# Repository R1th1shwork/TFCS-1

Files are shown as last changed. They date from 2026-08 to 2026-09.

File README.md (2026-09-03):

# TFCS-1: Teensy Flight Computer & Climate Suite



> **WARNING: Active Development**Expect changes to hardware wiring, sensor selection, and software builds as this project continues through testing and validation.

> **AI Transparency Disclosure**All system architecture, hardware selection, circuit design, and physical builds are designed and wired by me. AI was used only as a sounding board for code formatting, debugging, and documentation polish. The soldering, hardware decisions, and flight-control logic are human-built.

**TFCS-1** is an open-source flight controller and environmental sensing platform built around the **Teensy 4.1**. It combines flight-control sensing, servo control, radio input, telemetry, and atmospheric data logging for experimental aircraft and environmental monitoring.

- **GitHub:** [github.com/R1th1shwork/TFCS-1](https://github.com/R1th1shwork/TFCS-1)

- **Stardance:** [stardance.hackclub.com/projects/49798](https://stardance.hackclub.com/projects/49798)

---

## Project Assets

### Images and Media

| File | Description |
| --- | --- |
| `Assets/ten.png` | Teensy 4.1 microcontroller, the brain of TFCS-1 |
| `Assets/rf.jpeg` | RadioLink R12F SBUS receiver test |
| `Assets/icm.jpeg` | ICM-20948 9-DOF IMU, borrowed for development |
| `Assets/schematics.jpeg` | Earlier wiring diagram for the flight controller |

### Videos

| File | Description |
| --- | --- |
| `TFCS-1_Stardance_Ailerons.mp4` | Aileron servo demonstration |
| `ailerons test.mp4` | Aileron test footage |

> **Full Video Demos:** [Google Drive Folder](https://drive.google.com/drive/folders/199b-1cK7TjypQ-vlO30ZAJLWgoHDL5SH)

### Firmware and Hardware Design Files

| File | Description |
| --- | --- |
| `TFCS-1_All_Surfaces.ino` | Flight-controller code for ailerons, elevator, and rudder |
| `TFCS_1_SBUS.ino` | RadioLink SBUS receiver test code |
| `Codes/New FC.kicad_sch` | Current KiCad schematic for the flight-controller architecture |

The current schematic is included in the `Codes` directory. It documents the planned controller, power, sensor, receiver, telemetry, and servo connections. The schematic is being updated as the sensor suite is tested and final component choices are confirmed.

---

## Table of Contents

- [Why I Built This](#why-i-built-this)

- [Story / Behind the Scenes](#story--behind-the-scenes)

- [Current Status](#current-status)

- [Hardware](#hardware)

- [Wiring Instructions](#wiring-instructions)

- [Schematic and PCB Design](#schematic-and-pcb-design)

- [Control Surfaces](#control-surfaces)

- [Software](#software)

- [Setup](#setup)

- [Telemetry](#telemetry)

- [Challenges and Fixes](#challenges-and-fixes)

- [Roadmap](#roadmap)

- [Future Funding and BOM](#future-funding-and-bom)

- [Equipment Status](#equipment-status)

- [Testing Plan](#testing-plan)

- [Contributing](#contributing)

- [Author](#author)

- [Acknowledgments](#acknowledgments)

- [Disclaimer](#disclaimer)

---

## Why I Built This

I am a 16-year-old maker obsessed with flight. I did not start with a kit or a pre-built flight controller. I started with a soldering iron, a breadboard, and the determination to understand every wire and every line of code that keeps a plane in the air.

This project exists because:

- I want to **learn** flight-controller tuning, sensor fusion, and embedded systems from first principles.

- I want to **open-source** every finding, failure, and fix so the next builder does not start from zero.

- I believe the best way to learn is to build, break, and rebuild, one test at a time.

---

## Story / Behind the Scenes

### The Beginning

The Teensy 4.1 arrived from my tutor, a 600 MHz board I had been reading about for months. The first time the orange LED blinked, I knew this was real. Then came the ICM-20948, the 9-DOF IMU that was supposed to be the heart of the system. It did not work reliably. An I2C scan found it at `0x68`, but the moment I tried to read data, the bus could hang. No pull-up resistors, possible logic-level issues, or simply inexperience could have contributed. I spent hours staring at wires that refused to talk.

### The Breakthrough

I switched to the MPU-6050. Cheap, common, and suddenly it just worked. Data flowed. Numbers moved when I tilted the board. I connected the first servo and watched a control surface respond to my hands. That moment, seeing physics turn into servo motion, is when TFCS-1 became more than a project. It became a flight controller.

### The Reality Check

Not everything worked. Pin 8 was unreliable for my servo setup. The ICM-20948 still needs further debugging and testing. I salvaged wings from an old RC plane, pulled servos from crashed airframes, and learned that “working” in electronics often means “working after the 47th try.” Every buzz, every jitter, and every frozen I2C bus taught me something.

The sensor suite is also evolving through testing. I am currently validating the PMS5003, SCD40, MQ-135, BME680, GPS, compass, and other modules before committing to the final PCB layout. This is intentional: I want the final board to be based on tested sensors rather than assumptions.

### Why Open Source?

Because I learned from open-source projects. Because someone else out there is 16 years old, staring at a breadboard, wondering why their sensor will not respond. This is for them. This is for the builders who learn by breaking things.

---

## Current Status

| Module | Status | Notes |
| --- | --- | --- |
| MPU-6050 roll and pitch | Done | Working reliably on the bench |
| Elevator servo | Done | Pin 5, 40–140 degrees |
| Rudder servo | Done | Pin 6, 60–120 degrees |
| Aileron servos | Done | Pins 9 and 10, 40–140 degrees |
| Low-pass filter | Done | `ALPHA = 0.15` reduces jitter |
| Deadband | Done | `0.8 degrees` reduces servo buzzing |
| Serial telemetry | Done | 115200 baud |
| Flight-control logic | Bench tested | Roll and pitch correction logic implemented |
| RadioLink SBUS receiver | Done | Six channels reading correctly |
| PMS5003 particulate sensor | Tested | PM1.0, PM2.5, and PM10 data received |
| SCD40 CO2 sensor | Tested | CO2, temperature, and humidity data received |
| MQ-135 gas sensor | Tested | Raw analogue gas-trend data received; calibration still required |
| BME680 | Planned | To be integrated after current sensor validation |
| M10 GPS | Planned / integrating | UART position and flight-data testing |
| Compass | Planned / integrating | I2C heading testing and calibration required |
| SD-card logging | In progress | CSV logging architecture planned |
| RF telemetry | In progress | Packet architecture being tested |
| OLED ground receiver | Planned | Nano-based receiver display |
| Teensy 4.1 integration | In progress | Borrowed development unit |
| ICM-20948 9-DOF fusion | In progress | Needs debugging and validation |
| FPV system | Planned | 5.8 GHz camera and transmitter |
| Current schematic | Added | `Codes/New FC.kicad_sch` |
| Final custom PCB | Planned | Will be designed after the final sensor set is validated |

**Current test platform:** E-flite Apprentice S1E, 1500 mm wingspan, 840 KV motor.

> **Note:** The Apprentice is heavily damaged after a crash and cannot currently be flown. It is being used as a bench-test body and mechanical reference. Final flight testing will require an appropriate airframe, supervision, and any permissions required by the test location.

---

## Hardware

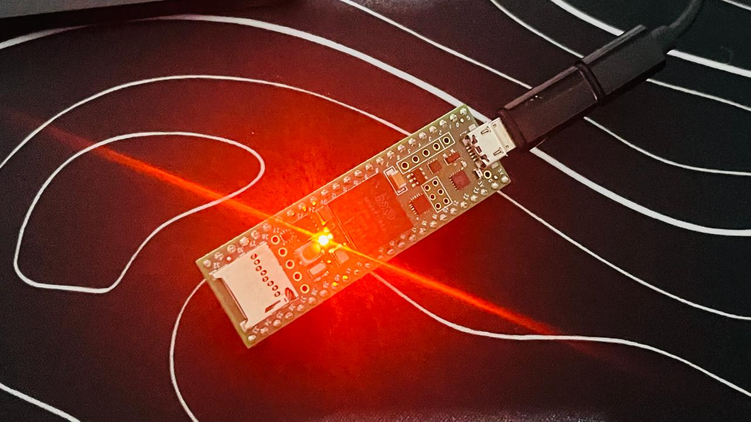
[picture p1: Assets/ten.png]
Teensy 4.1 Microcontroller


### Compute and Avionics

| Component | Model | Specs | Status |
| --- | --- | --- | --- |
| Primary controller | Teensy 4.1 | 600 MHz ARM Cortex-M7, 1 MB RAM | **BORROWED** |
| Development controller | Arduino Uno R3 | 16 MHz ATmega328P | Owned |
| Current IMU | MPU-6050 | 6-DOF accelerometer and gyroscope | Owned |
| Future IMU | ICM-20948 | 9-DOF accelerometer, gyroscope, and magnetometer | **BORROWED** |
| GPS module | M10-based GPS module | UART, position and timing data | Being integrated |
| Compass | External I2C magnetometer | Heading reference | To be tested |
| Radio receiver | RadioLink R12F | SBUS receiver | Owned |
| Radio transmitter | RadioLink T12D | 12 channels | Owned |
| Environmental sensors | PMS5003, SCD40, MQ-135, BME680 | Particulate, CO2, gas-trend, and atmospheric data | Being validated |

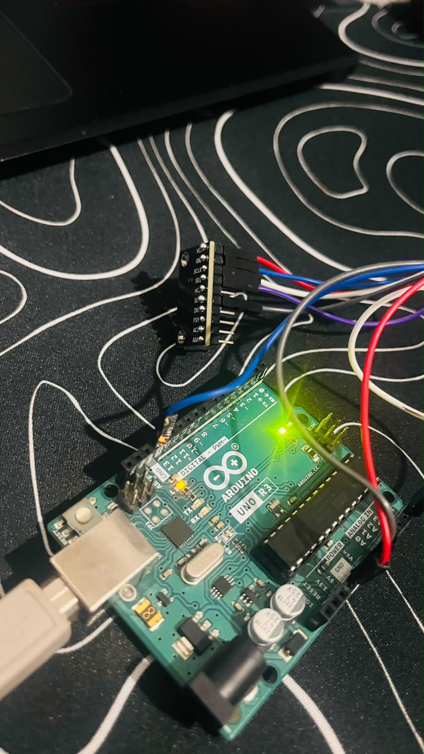
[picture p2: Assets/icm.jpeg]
ICM-20948 9-DOF IMU


### Actuators

| Component | Pin | Range | Status |
| --- | --- | --- | --- |
| Left aileron | 9 | 40–140 degrees | Owned |
| Right aileron | 10 | 40–140 degrees | Owned |
| Elevator | 5 | 40–140 degrees | Owned |
| Rudder | 6 | 60–120 degrees | Owned |
| ESC | — | 30 A with BEC | Owned |

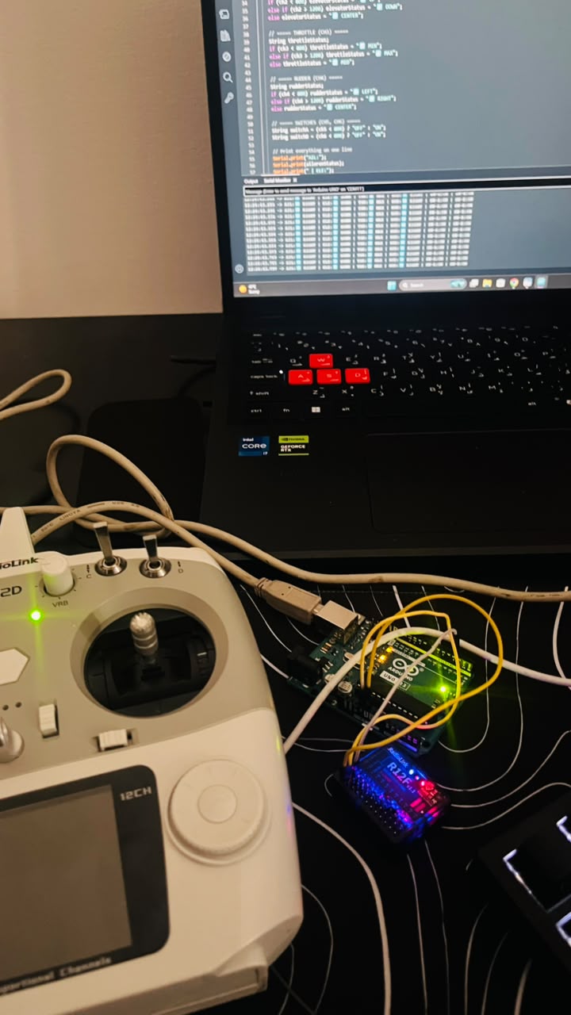
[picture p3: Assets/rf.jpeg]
RadioLink R12F SBUS Receiver


### Power

| Component | Specs | Status |
| --- | --- | --- |
| UBEC | 7 A, 5 V output | Owned |
| Battery | 4S 3000 mAh | To be purchased or supplied for final flight testing |
| Power distribution | Custom board or final PCB power section | Planned |

### Current and Planned Additions

- [x] Current schematic added to `Codes/New FC.kicad_sch`

- [x] PMS5003 tested

- [x] SCD40 tested

- [x] MQ-135 tested as a raw gas-trend sensor

- [ ] Teensy 4.1 full integration

- [ ] BME680 integration

- [ ] M10 GPS integration

- [ ] Compass integration and calibration

- [ ] MicroSD card logging

- [ ] RF telemetry

- [ ] OLED ground receiver

- [ ] FPV camera and VTX

- [ ] Final sensor validation

- [ ] Final custom PCB design and fabrication

- [ ] Airspeed sensor integration

- [ ] Professional barometer integration

---

## Wiring Instructions

> **Note:** Pin assignments below describe the current development architecture. They may change as the final sensor and controller configuration is validated.

### MPU-6050 and ICM-20948

| Pin | Teensy 4.1 | Arduino Uno | Function |
| --- | --- | --- | --- |
| VCC | 3.3 V | 3.3 V | Check the breakout-board voltage requirements |
| GND | GND | GND | Ground |
| SDA | 18 | A4 | I2C data |
| SCL | 19 | A5 | I2C clock |

### M10 GPS Module

| GPS pin | Controller connection | Function |
| --- | --- | --- |
| VCC | Regulated supply specified by the module | Power |
| GND | Common GND | Ground |
| TX | Hardware UART RX | GPS NMEA data |
| RX | Hardware UART TX, optional | GPS configuration |
| SDA/SCL | Only if the module is configured for I2C | Optional alternate interface |
| PPS | Optional digital input | Timing pulse |

The GPS and PMS5003 are both serial devices. They must not share the same UART receive pin at the same time. A second UART, a tested software UART, an external UART bridge, or a second controller may be required for simultaneous use.

### Compass

| Compass pin | Controller connection | Function |
| --- | --- | --- |
| VCC | Correct regulated voltage for the breakout | Power |
| GND | Common GND | Ground |
| SDA | I2C SDA | Heading data |
| SCL | I2C SCL | I2C clock |

The compass and MPU6050 can share the same I2C bus if their addresses do not conflict. The compass must be mounted away from motors, ESCs, high-current battery wires, and ferromagnetic hardware. It requires calibration and tilt-compensated sensor fusion before its output can be used as a reliable aircraft yaw estimate.

### RadioLink R12F SBUS

| Pin | Teensy 4.1 | Arduino Uno | Function |
| --- | --- | --- | --- |
| VCC | 5 V | 5 V | Power |
| GND | GND | GND | Ground |
| SBUS signal | Pin 3 or a suitable hardware serial input | Pin 3 during development | Receiver data |

### Servos

| Component | Teensy 4.1 | Arduino Uno | Wire/function |
| --- | --- | --- | --- |
| Elevator signal | Pin 5 | Pin 5 | Orange signal wire |
| Rudder signal | Pin 6 | Pin 6 | Orange signal wire |
| Left aileron signal | Pin 9 | Pin 9 | Orange signal wire |
| Right aileron signal | Pin 10 | Pin 10 | Orange signal wire |
| Servo VCC | External 5 V BEC | External 5 V BEC | Red wire |
| Servo GND | Common GND | Common GND | Brown or black wire |

### Power

| Connection | Description |
| --- | --- |
| UBEC input | Battery input within the UBEC’s specified range |
| UBEC output | Regulated 5 V for the controller or approved peripherals |
| Sensor rails | Use the correct 3.3 V or 5 V rail for each breakout board |
| RF module rail | Use a stable regulated 3.3 V supply and local decoupling |
| Ground | Connect all signal-system grounds together |

Never connect a raw LiPo battery directly to a controller or sensor. Always verify polarity, voltage, and current capacity before powering the system.

### Quick Reference

| Component | Power | Ground | Signal |
| --- | --- | --- | --- |
| MPU-6050 | 3.3 V or approved breakout voltage | GND | SDA to A4, SCL to A5 |
| Compass | Approved breakout voltage | GND | SDA to A4, SCL to A5 |
| M10 GPS | Approved module voltage | GND | UART TX to controller RX |
| RadioLink R12F | 5 V | GND | SBUS input |
| PMS5003 | Usually 5 V | GND | UART TX input |
| SCD40 | Approved breakout voltage | GND | SDA to A4, SCL to A5 |
| MQ-135 | Usually 5 V | GND | AOUT to analogue input |
| Elevator | External 5 V BEC | Common GND | Pin 5 |
| Rudder | External 5 V BEC | Common GND | Pin 6 |
| Left aileron | External 5 V BEC | Common GND | Pin 9 |
| Right aileron | External 5 V BEC | Common GND | Pin 10 |

---

## Schematic and PCB Design

The current schematic has now been added to the repository at:

```
Codes/New FC.kicad_sch
```
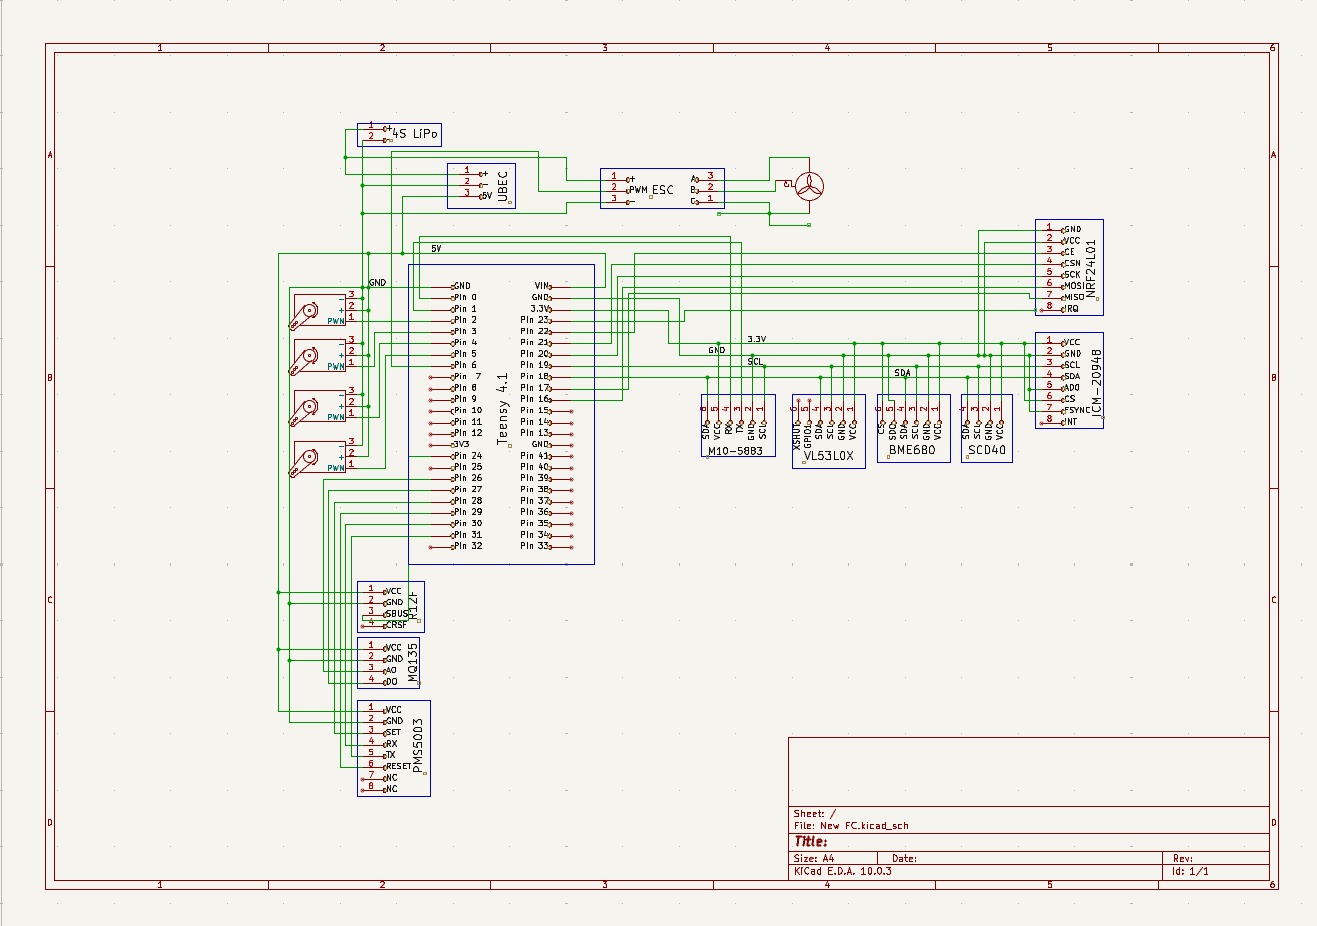
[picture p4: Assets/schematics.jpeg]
schematics


This file represents the current electrical architecture and is being updated as the sensor suite is tested. It includes the controller, power rails, sensor interfaces, receiver input, telemetry interfaces, and servo outputs.

The final PCB has **not** yet been fabricated. This is intentional because the sensor set and exact component choices are still being validated. The final board should be based on tested sensors, confirmed footprints, verified voltage levels, and measured power requirements.

The next hardware-design stage is a modular Rev A PCB design with removable connectors for the sensors. This allows the sensor models to be changed without redesigning the complete board. After the final sensor set is confirmed through bench testing, a final Rev B PCB will be designed and fabricated.

### Planned PCB interfaces

| Interface | Purpose |
| --- | --- |
| Controller headers | Teensy 4.1 connection |
| I2C headers | MPU6050, compass, SCD40, BME680, and compatible sensors |
| GPS UART header | M10 GPS connection |
| Environmental UART header | PMS5003 connection |
| Analogue header | MQ-135 and future analogue sensors |
| SPI header | SD card and telemetry peripherals |
| SBUS header | RadioLink receiver |
| Servo headers | Aileron, elevator, and rudder outputs |
| Power section | Battery input, regulated 5 V, regulated 3.3 V, protection, and test points |

> **Design status:** Schematic added. Final PCB fabrication is pending final sensor validation and confirmed component selection.

---

## Control Surfaces

| Axis | Surface | Pin | Range | Response |
| --- | --- | --- | --- | --- |
| Pitch | Elevator | 5 | 40–140 degrees | Nose attitude correction |
| Yaw | Rudder | 6 | 60–120 degrees | Directional correction |
| Roll | Left aileron | 9 | 40–140 degrees | Mirrored roll response |
| Roll | Right aileron | 10 | 40–140 degrees | Mirrored roll response |

**Neutral position for all servos:** 90 degrees.

---

## Software

### Current Features

| Feature | Implementation | Status |
| --- | --- | --- |
| I2C communication | `Wire` library | Done |
| Angle calculation | Accelerometer-based roll and pitch | Done |
| Digital filtering | Exponential moving average, `ALPHA = 0.15` | Done |
| Deadband | `0.8 degrees` | Done |
| Servo control | Four servos | Bench tested |
| Telemetry output | Serial Monitor at 115200 baud | Done |
| SBUS receiver | RadioLink R12F, six channels | Done |
| PMS5003 reading | Serial particulate data | Tested |
| SCD40 reading | I2C CO2, temperature, and humidity | Tested |
| MQ-135 reading | Analogue raw trend data | Tested; calibration pending |

### Control Loop

| Parameter | Value |
| --- | --- |
| Loop rate | 50 Hz, 20 ms |
| Filter | Exponential moving average |
| Alpha | 0.15 |
| Deadband | 0.8 degrees |
| Telemetry baud | 115200 |

### Key Code Snippet

```cpp
// Exponential Moving Average Filter
filteredPitch = (ALPHA * rawPitch) + ((1.0 - ALPHA) * filteredPitch);

// Deadband to prevent servo buzzing
if (abs(filteredPitch) < 0.8) {
  elevatorPos = 90;
}

// Map to servo positions
elevatorPos = map(filteredPitch, -20, 20, 140, 40);
```

---

## Setup

### 1. Install Libraries

```cpp
#include <Wire.h>    // I2C communication
#include <Servo.h>   // Servo control
#include <sbus.h>    // SBUS receiver
```

Additional sensor libraries will be added once each sensor is confirmed and the final controller platform is locked.

### 2. Upload

1. Select the correct board, either **Arduino Uno** for development or **Teensy 4.1** for the main controller.

1. Select the correct COM port.

1. Upload the firmware.

1. Open Serial Monitor at **115200 baud**.

### 3. Bench Test Procedure

| Test | Expected behavior |
| --- | --- |
| Hold board level | Servos remain near 90 degrees |
| Tilt nose down | Elevator responds in the configured direction |
| Tilt nose up | Elevator responds in the configured direction |
| Tilt left | Ailerons respond in opposite directions |
| Tilt right | Ailerons respond in opposite directions |
| Rotate compass | Heading changes after calibration |
| Expose PMS5003 to changing air conditions | PM readings respond after the sensor’s response delay |
| Change CO2 conditions safely | SCD40 reading changes over time |
| Move MQ-135 near a controlled test source | Raw trend value changes; no uncalibrated ppm claim |

All motor and propeller testing must be performed safely and separately from sensor and servo bench testing.

---

## Telemetry

```
P:0.0 deg (Elev:90 deg) | R:0.0 deg (Rudd:90 deg) | A:90 deg
P:-5.2 deg (Elev:77 deg) | R:0.0 deg (Rudd:90 deg) | A:77 deg
P:10.1 deg (Elev:65 deg) | R:0.0 deg (Rudd:90 deg) | A:65 deg
```

**Key:**

- `P`: Filtered pitch angle in degrees

- `Elev`: Elevator position

- `R`: Filtered roll angle in degrees

- `Rudd`: Rudder position

- `A`: Aileron position

The planned environmental telemetry will include CO2, PM1.0, PM2.5, PM10, temperature, humidity, pressure, GPS position, battery state, and sensor-health flags. The RF packet layout will be kept within the selected radio’s payload limit, with environmental and flight-status data split into separate packets where necessary.

---

## Challenges and Fixes

| Challenge | Solution |
| --- | --- |
| ICM-20948 not working reliably | Switched to the MPU-6050 for current development |
| Servo jitter | Added low-pass filtering with `ALPHA = 0.15` |
| Servo buzzing at level | Added a `0.8 degree` deadband |
| Pin 8 unreliable for a servo | Switched to Pins 5, 6, 9, and 10 |
| MPU not responding | Fixed wiring and added debug code |
| Servos moving in the same direction | Added mirrored mounting logic |
| I2C hanging | Improved wiring and added pull-up resistors where required |
| SBUS receiver not reading | Corrected signal wiring and installed the SBUS library |
| PMS5003 serial testing | Tested the sensor independently before integration |
| Changing sensor list | Using modular connectors and delaying final PCB fabrication |
| RF payload size | Splitting telemetry into smaller packets within the radio limit |

---

## Roadmap

### Immediate

- [x] Add the current KiCad schematic to `Codes/New FC.kicad_sch`

- [x] Test the PMS5003

- [x] Test the SCD40

- [x] Test the MQ-135 raw reading

- [ ] Complete Teensy 4.1 integration

- [ ] Integrate the M10 GPS

- [ ] Integrate and calibrate the compass

- [ ] Integrate the BME680

- [ ] Add SD-card CSV logging

- [ ] Test RF telemetry

- [ ] Build the OLED ground receiver

### Next Stage

- [ ] Validate the complete sensor suite on the bench

- [ ] Record repeatable environmental test data

- [ ] Create the modular Rev A PCB layout

- [ ] Verify all footprints, voltage rails, and power requirements

- [ ] Test the full controller with motors disconnected

- [ ] Integrate the final sensor set into the aircraft

### Future

- [ ] Fabricate the final custom PCB after sensor validation

- [ ] Full 6-axis sensor fusion using Madgwick or Mahony filtering

- [ ] MAVLink telemetry protocol

- [ ] Waypoint navigation

- [ ] Ground station for Android or PC

- [ ] AI-assisted flight tuning

- [ ] Airspeed-sensor integration

- [ ] Professional barometer integration

- [ ] FPV system integration

- [ ] Authorised real-flight testing

---

## Future Funding and BOM

With funding from Stardance, the sensor suite will become a much more complete and testable system. The funding will help me purchase higher-quality components and validate the Teensy 4.1 flight controller under real test conditions.

The exact sensor selection is still being validated. I have intentionally kept the final PCB fabrication separate from the initial sensor testing so that the final board is based on confirmed components rather than untested assumptions.

### Full BOM

| Item | Description | Qty | Price (AED) | Price (USD) | Link |
| --- | --- | --- | --- | --- | --- |
| SLONWAKE 1W VTX + 1500TVL Camera | 5.8 GHz 48CH FPV transmitter with camera | 1 | 151.95 | 41.36 | [AliExpress](https://ar.aliexpress.com/item/1005008177732104.html) |
| GY-63 MS5611 Barometer | High-precision air-pressure sensor module | 1 | 16.69 | 4.54 | [AliExpress](https://ar.aliexpress.com/item/32981169861.html) |
| MS4525DO Airspeed Sensor | Differential-pressure module with Pitot tube kit | 1 | 107.19 | 29.18 | [AliExpress](https://ar.aliexpress.com/item/1005009943453550.html) |
| 4S 3000 mAh LiPo Battery | 14.8 V, 60C RC battery with XT60 connector | 1 | 141.86 | 38.62 | [AliExpress](https://ar.aliexpress.com/item/1005010778424365.html) |
| SX1278 LoRa Ra-01 Module | 433 MHz long-range telemetry module, pack of 2 | 2 | 19.60 | 5.34 | [AliExpress](https://ar.aliexpress.com/item/1005007345198584.html) |
| BSS138 Logic Level Converter | Bidirectional 4-channel 3.3 V to 5 V converter | 1 | 10.00 | 2.72 | [Noon](https://www.noon.com/uae-en/bss138-logic-level-converter-bi-directional-4-channel-3-3v-5v-bi-directional/ZF14BBDADB787D14A80DAZ/p/) |
| MPU-9250 9-Axis IMU | Gyroscope, accelerometer, and magnetometer sensor | 1 | 20.00 | 5.44 | [Noon](https://www.noon.com/uae-en/mpu-9250-gy-9250-9-axle-16-bit-gyroscope-acceleration-magnetic-sensor-3-5v/ZAC72641E953208FED97AZ/p/) |
| BMP280 Barometer | Temperature and atmospheric-pressure sensor | 1 | 6.02 | 1.64 | [AliExpress](https://ar.aliexpress.com/item/1005012294605575.html) |
| AliExpress Shipping | Shipping fee for AliExpress order | 1 | 32.28 | 8.79 | — |
| UAE Import Tax | Estimated import tax and clearance fees | 1 | 40.00 | 10.90 | — |
| **GRAND TOTAL** |  |  | **541.38** | **147.50** |  |

*Exchange rate used in the original estimate: 1 USD = 3.6725 AED.*

### What This Funding Will Unlock

- Complete Teensy 4.1 flight-controller integration

- Higher-quality IMU, barometer, airspeed, telemetry, and FPV hardware

- Real bench and authorised flight testing

- Environmental sensor validation and data logging

- Modular PCB design followed by final PCB fabrication after the sensor set is confirmed

- Open-source release of firmware, schematic files, and future PCB design files

---

## Equipment Status

| Component | Status | Source |
| --- | --- | --- |
| Teensy 4.1 | **BORROWED** | Tutor, three months |
| ICM-20948 | **BORROWED** | Tutor, three months |
| MPU-6050 | Owned | — |
| Arduino Uno | Owned | — |
| M10 GPS module | Owned or being integrated | — |
| E-flite Apprentice S1E | **BROKEN** | Crashed, used for bench testing |
| Servos, four units | Owned | Recovered from old plane |
| 7 A UBEC | Owned | — |
| ESC | Owned | — |
| RadioLink T12D and R12F | Owned | Recently purchased |

**Special thanks:** A huge thank you to my tutor for lending me the expensive components, especially the Teensy 4.1 and ICM-20948. Without that support, this project would not be possible.

---

## Testing Plan

The project is being tested in stages. First, each sensor and interface is tested independently. Next, the controller, telemetry, logging, and sensor suite are tested together on the bench. After the final sensor choices are confirmed, the modular PCB design will be updated and the final PCB can be fabricated.

For flight testing, I will use an appropriate airframe and conduct testing only with suitable supervision, safety procedures, and any permissions required by the location. The damaged Apprentice is not being treated as a flyable aircraft.

### Validation evidence planned

- Sensor readings recorded over time

- CSV logs from the SD card

- GPS position and timing data

- IMU and compass calibration results

- RF packet-loss and range tests

- Servo-response and control-surface tests

- Power-rail voltage measurements

- Photographs of the assembled electronics

- Schematic and PCB design exports

- Flight-test videos and logs when authorised and safe

---

## Contributing

This is open-source and contributions are welcome.

### How to Contribute

1. Fork the repository.

1. Create a feature branch.

1. Commit your changes.

1. Push the branch.

1. Open a Pull Request with a clear explanation of the changes.

### Areas Needing Help

- Testing on different hardware

- Documentation improvements

- Modular PCB design

- Sensor-fusion algorithms

- Telemetry protocols

- Ground-station software

- Environmental-data visualisation

- Flight-test planning and safety review

---

## Author

**Rithish** — 16-year-old maker with a passion for flight and embedded systems.

- **GitHub:** [github.com/R1th1shwork](https://github.com/R1th1shwork)

- **Project:** [github.com/R1th1shwork/TFCS-1](https://github.com/R1th1shwork/TFCS-1)

- **Stardance:** [stardance.hackclub.com/projects/49798](https://stardance.hackclub.com/projects/49798)

---

## Acknowledgments

- **My tutor** — For lending critical components.

- **The Arduino community** — For open-source libraries and support.

- **The Teensy community** — For the incredible Teensy platform.

- **Open-source hardware and software contributors** — For making it possible to learn by building.

---

## Disclaimer

> This project is for educational and experimental purposes only. Always test flight hardware thoroughly before actual flight operations. Follow applicable aviation, venue, and safety requirements. The author is not responsible for damages or injuries resulting from the use of this hardware or software.

---

<p align="center">
<i>Built with passion, powered by curiosity, and tested on borrowed equipment.</i>  

  <b>Fly safe, have fun, and learn something new.</b>
</p> <p align="right"><i>Last Updated: September 2026</i></p>

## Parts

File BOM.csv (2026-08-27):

Item | Description | Qty | Price (AED) | Price (USD) | Link
SLONWAKE 1W VTX + 1500TVL Camera | 5.8GHz 48CH FPV Transmitter with Camera | 1 | 151.95 | 41.36 | https://ar.aliexpress.com/item/1005008177732104.html
GY-63 MS5611 Barometer | High Precision Air Pressure Sensor Module | 1 | 16.69 | 4.54 | https://ar.aliexpress.com/item/32981169861.html
MS4525DO Airspeed Sensor | Differential Pressure Module with Pitot Tube Kit | 1 | 107.19 | 29.18 | https://ar.aliexpress.com/item/1005009943453550.html
4S 3000mAh LiPo Battery | 14.8V 60C RC Battery with XT60 Connector | 1 | 141.86 | 38.62 | https://ar.aliexpress.com/item/1005010778424365.html
SX1278 LoRa Ra-01 Module | 433MHz Long-range Telemetry Module (Pack of 2) | 2 | 19.60 | 5.34 | https://ar.aliexpress.com/item/1005007345198584.html
BSS138 Logic Level Converter | Bi-Directional 4-Channel 3.3V-5V | 1 | 10.00 | 2.72 | https://www.noon.com/uae-en/bss138-logic-level-converter-bi-directional-4-channel-3-3v-5v-bi-directional/ZF14BBDADB787D14A80DAZ/p/
MPU-9250 9-Axle IMU | Gyro + Accelerometer + Magnetometer Sensor | 1 | 20.00 | 5.44 | https://www.noon.com/uae-en/mpu-9250-gy-9250-9-axle-16-bit-gyroscope-acceleration-magnetic-sensor-3-5v/ZAC72641E953208FED97AZ/p/
BMP280 Barometer | Temperature + Humidity + Atmospheric Pressure Sensor (3.3V) | 1 | 6.02 | 1.64 | https://ar.aliexpress.com/item/1005012294605575.html
AliExpress Shipping | Shipping Fee for AliExpress Order | 1 | 32.28 | 8.79
UAE Import Tax | Estimated Import Tax & Clearance Fees (5% + Handling) | 1 | 40.00 | 10.90
TOTAL ITEMS
GRAND TOTAL (AED) |  |  | 541.38 | 147.50

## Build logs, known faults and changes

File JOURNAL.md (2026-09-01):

# TFCS-1 Project Journal

**Project:** TFCS-1: Teensy Flight Computer & Climate Suite  
**Author:** Rithish (16-year-old maker)  
**Total Time Spent:** ~11 hours 10 minutes (logged)

---

## 📖 About This Journal

This journal documents the complete journey of building TFCS-1 - from unboxing the Teensy 4.1 to finalizing the BOM for Stardance submission. Every dev log represents a real session of work, including successes, failures, and lessons learned.

---

## Dev Log #17 - Sensor Testing

**Date:** September 1, 2026  
**Time Spent:** 29m  
**✅ Checklist:**
- [x] PMS5003 tested and working
- [x] SCD40 wiring mapped out
- [x] MQ-135 wiring mapped out
- [x] Test code written for SCD40 + MQ-135
- [ ] Combine all sensors with RF telemetry (next step)
- [ ] SD logging integration (next step)
- [ ] OLED receiver integration (next step)

**Details:**  
Tested the PMS5003 and it works. Plan is to add sensors one by one so troubleshooting is easier. Mapped out wiring for SCD40 (I2C bus) and MQ-135 (A0, 5V). Wrote test code that reads CO2, temp, humidity from SCD40 and raw gas readings from MQ-135. MQ-135 will be used as a relative gas-trend sensor unless calibrated later. Next up is combining everything with RF telemetry, SD logging, and OLED.

---

## Dev Log #16 - RF Packet Designed & Code Ready!

**Date:** August 31, 2026  
**Time Spent:** 24m  
**✅ Checklist:**
- [x] RF telemetry packet designed (55 bytes)
- [x] All sensors packed into packet
- [x] Full integration code written
- [x] SD logging included
- [x] Web server included
- [ ] Bench testing (tomorrow)
- [ ] Upload to GitHub (after testing)

**Details:**  
Today I finished designing the full RF telemetry packet for the NRF24L01. Got all sensors packed into 55 bytes - MPU6050, BN-880 GPS, SCD40, BME680, PMS5003, MQ135, and MS4525DO. All neatly packed and ready to send to the ground station. The full integration code is written with SD logging, web server, and everything. Will test it all tomorrow on the bench and upload to GitHub once it's working.

---

## Dev Log #15 - MPU + SBUS + PID Code Ready!

**Date:** August 30, 2026  
**Time Spent:** 39m  
**✅ Checklist:**
- [x] Full MPU + SBUS + PID code written
- [x] Code uploaded to GitHub
- [x] MB102 power supply researched
- [ ] Aileron testing (tomorrow)

**Details:**  
Wrote and uploaded the full MPU + SBUS + PID code to GitHub. Got roll and pitch data from MPU, sticks from RadioLink, and PID corrections calculated. Tomorrow I'll test it properly with just the ailerons to check if the self-correcting actually works. Also did some research on the MB102 power supply and the Uno to see if it helps with bench testing. Just research for now, nothing tested yet. But good progress overall. More testing tomorrow.

---

## Dev Log #14 - Mercury OS Planning (Travel Mode)

**Date:** August 29, 2026  
**Time Spent:** 18m  
**✅ Checklist:**
- [x] Mercury OS planned out
- [x] Failsafe priority system designed
- [x] Notes taken for all features
- [ ] Code implementation (pending)

**Details:**  
Traveling right now so no hardware today, had to work with my phone but I used the time to plan out my own FC OS called Mercury and also how safefail priority is a main thing. Just planned out and took notes but the plans and the direction is solid. The OS will handle failsafe first, then flight control, sensor fusion, telemetry, logging, and housekeeping in a priority-based system.

---

## Dev Log #13 - Shifted Focus & Resubmitted!

**Date:** August 28, 2026  
**Time Spent:** ~45m  
**✅ Checklist:**
- [x] Project direction shifted from airframe to flight controller
- [x] BOM completely redesigned
- [x] README updated with new focus
- [x] JOURNAL updated
- [x] KiCad schematic uploaded
- [x] Funding resubmitted for $147.50 USD

**Details:**  
After reading the Stardance feedback, I completely shifted my project direction. Instead of building an airframe, I am now focusing entirely on the flight controller itself. I updated everything - BOM, README, journal, schematic, code. Just resubmitted the funding request for $147.50 USD. This funding will help me build a proper Teensy 4.1 flight controller with IMU, airspeed, barometer, telemetry and FPV. I really hope this gets approved. Fingers crossed.

---

## Dev Log #12 - Finalizing Everything For Submission!

**Date:** August 27, 2026  
**Time Spent:** 40m 55s  
**✅ Checklist:**
- [x] BOM finalized with all components
- [x] Prices in both AED and USD
- [x] Sensor list locked in

**Details:**  
Busy day today! Got the final BOM ready with all components, links, and prices in both AED and USD. Total comes to ~$147.50 USD including shipping and import tax. Finally locked in the sensor list: MPU-9250 for orientation, BMP280 and MS5611 for altitude, MS4525DO for airspeed, and the SLONWAKE 1W VTX for long-range FPV. Also got the logic level converter from Noon to safely connect everything to the Teensy. Tomorrow is the big day - gotta upload everything to GitHub for the Stardance submission. Need to add the BOM CSV, the README, the journal, and the demo videos. Still need to figure out the CAD/STEP file situation and the wiring diagram. Feeling good about where the project is at. One more push and it's done!

---

## Dev Log #11 - Radio Receiver Is Alive!

**Date:** August 26, 2026  
**Time Spent:** 21m  
**✅ Checklist:**
- [x] RadioLink receiver wired up
- [x] SBUS signal to pin 3
- [x] All 6 channels reading in Serial Monitor

**Details:**  
Finally got the RadioLink receiver working with the Arduino! Connected the SBUS signal to pin 3 and got all 6 channels showing up in the Serial Monitor. Aileron, Elevator, Throttle, Rudder, and switches all reading properly. Took forever to figure out the wiring and the right library but it's done now. Next step is merging the MPU data with the radio input so the flight controller can correct my sticks and keep the plane stable. Both systems work separately, now just gotta combine them. Feels good to finally have a real transmitter.

---

## Dev Log #10 - Funding Submitted!

**Date:** August 25, 2026  
**Time Spent:** 49m 50s  
**✅ Checklist:**
- [x] Stardance funding request submitted
- [x] $260 USD requested
- [x] BOM ready

**Details:**  
Just submitted the Stardance funding request for $260 USD. This is it man. If it gets approved, the dream build becomes real. Xfly X1300 airframe, 4S battery, motor, ESC, servos - everything I need. Teensy 4.1 and ICM-20948 are already borrowed from my tutor. The Apprentice is wrecked anyway so the X1300 will be the real deal. Been working on this for weeks. Soldering, coding, troubleshooting, failing, fixing, learning. This is the moment it all comes together. Fingers crossed.

---

## Dev Log #9 - README Done, Video Tomorrow, BOM Ready!

**Date:** August 24, 2026  
**Time Spent:** 53m  
**✅ Checklist:**
- [x] GitHub README updated
- [x] BOM list finalized
- [x] Dev logs removed from README

**Details:**  
Finally got the GitHub README fully updated, cleaned it up, removed the old dev logs, added the BOM as a future funding plan for Stardance, mentioned the Apprentice is broken and just a test body now, and put in notes about schematics and code coming soon. Also finalized the BOM list with all components and links in both AED and USD. Tomorrow I'm filming the Stardance demo video showing the bench setup with the MPU-6050 data streaming and servos moving. Feeling pretty good about where this project is heading. Just need to film that video and then we can focus on the Teensy 4.1 integration and getting everything on the actual airframe.

---

## Dev Log #8 - Back in Action

**Date:** August 23, 2026  
**Time Spent:** 1h 17m  
**✅ Checklist:**
- [x] Uno coded for rudder + ailerons
- [x] Both surfaces responding to MPU
- [x] README updated

**Details:**  
Back home finally! Got back to work on the TFCS-1. Coded the Uno to work with rudder and ailerons together - both control surfaces responding to MPU data now. Still need to test them all together on the actual airframe but the code logic is solid. Also updated the README on GitHub with all the project details, hardware specs, dev logs, and the whole story behind this build. Feels good to have proper documentation now. Next step is testing everything together on the bench and then moving to the Teensy 4.1 integration.

---

## Dev Log #7 - Travel Mode

**Date:** August 22, 2026  
**Time Spent:** 25m  
**✅ Checklist:**
- [x] Power system planned
- [x] ESC BEC → servos
- [x] UBEC → Teensy

**Details:**  
Traveling right now so no hardware today. But honestly still made progress. Planned out the whole power system - ESC BEC will power the servos and UBEC will power the Teensy. Both from the same battery with all grounds tied together. Got the code ready to test once I'm back home. Everything is planned out, just need to actually build it when I return. Really really want that plane man. Let's see.

---

## Dev Log #6 - Research Day

**Date:** August 21, 2026  
**Time Spent:** 27m  
**✅ Checklist:**
- [x] Researched airframes
- [x] X1300 identified as target

**Details:**  
Kinda felt off today so I didn't work on it much but I did some research on the airframe which I wanna actually test my systems on... TAAAADAA X1300 looks cool right?

---

## Dev Log #5 - Flight Controller Is Alive!

**Date:** August 20, 2026  
**Time Spent:** 42m  
**✅ Checklist:**
- [x] MPU-6050 reading roll data
- [x] Both wing servos working
- [x] Left wing UP on left tilt
- [x] Right wing DOWN on left tilt

**Details:**  
WE DID IT! The flight controller is officially WORKING! MPU-6050 is reading roll data and both wing servos move exactly how they should. Tilt left and left wing goes UP, right wing goes DOWN. Tilt right and left wing goes DOWN, right wing goes UP. It's beautiful watching them fight to keep the board level. Finally figured out the servo pin thing - pins 9 and 10 are the way to go, pin 8 was dead for some reason. Both servos get the same signal but since they're physically mirrored on the plane, one goes up and the other goes down. That's actually genius lol. Spent way too long on this but it's finally done.

---

## Dev Log #4 - Salvaged Wings!

**Date:** August 19, 2026  
**Time Spent:** 32m 53s  
**✅ Checklist:**
- [x] Wings salvaged from old plane
- [x] Left wing on pin 9
- [x] Right wing on pin 10
- [x] 40-90-140 deg movement

**Details:**  
Pulled out the wings from my old RC plane that's been sitting in the garage forever. Took the servos off them and tested both sides - left and right wings working smooth on pins 9 and 10. 90° neutral, 40° up, 140° down. No binding or breaking. Tomorrow we're adding the MPU to make them actually respond to the plane tilting. Old plane parts getting a new brain.

---

## Dev Log #3 - Data Is Flowing!

**Date:** August 18, 2026  
**Time Spent:** 21m  
**✅ Checklist:**
- [x] MPU-6050 working
- [x] Roll and pitch data streaming
- [x] Serial Monitor showing data

**Details:**  
I GOT DATA! MPU-6050 is streaming roll and pitch like crazy on the Serial Monitor. No servos yet but the numbers are moving when I tilt the board so that's a huge W. Next step is gonna be connecting this thing to the actual plane and seeing if the Uno can handle powering the servos without burning itself out lol. But for now we got data and that's what matters.

---

## Dev Log #2 - The Resistor Reality Check

**Date:** August 17, 2026  
**Time Spent:** 20m  
**✅ Checklist:**
- [x] ICM-20948 found at 0x68
- [x] Still hangs on read

**Details:**  
Came back today, tried the ICM again, still doesn't work without resistors. Spent like 15 minutes on it, ran the scanner, sensor shows up at 0x68 but still hangs when I try to read data. Same problem as yesterday. Need those 4.7kΩ pull-up resistors. Gonna order them and try again later. At least the Teensy still works lol.

---

## Dev Log #1 - A Brand New Day

**Date:** August 16, 2026  
**Time Spent:** 1h 7m  
**✅ Checklist:**
- [x] Teensy 4.1 unboxed and tested
- [x] Orange LED blinking
- [x] Serial Monitor working

**Details:**  
So today was the first real day of the TFCS-1 project and honestly it was a mix of hype and headache lol. I finally got my hands on a Teensy 4.1 from an old tutor of mine who lent it to me for a few weeks which is insane because this is literally the microcontroller I've been dreaming about for months. Plugged it in, got the orange LED blinking, uploaded a test sketch, and saw my messages pop up in the Serial Monitor so I know the board is alive and working which felt amazing. Then I tried wiring up the ICM-20948 IMU that he also lent me and uh yeah that didn't go so well. The I2C scanner couldn't find anything no matter what address I tried or how many times I rewired it. Tried it on an Arduino Uno first to avoid frying the Teensy and still nothing. Might be dead, might need a logic level converter, might just be my bad wiring I don't even know anymore lol. But you know what the Teensy works and that's what matters right now. Gonna take a break, sleep on it, and figure out the sensor stuff tomorrow.

---

## 📊 Summary

| Category | Total |
|---|---|
| **Total Time Logged** | ~11 hours 10 minutes |
| **Dev Log Entries** | 17 |
| **Days Worked** | 17 days |
| **Key Milestones** | Teensy working, MPU-6050 working, Servos working, RadioLink working, BOM finalized, Project shift complete, Mercury OS planned, RF packet designed, Sensor testing started |

---

## 🎯 Key Milestones Achieved

| Milestone | Dev Log | Date |
|---|---|---|
| Teensy 4.1 powered on | #1 | Aug 16 |
| ICM-20948 troubleshooting | #1, #2 | Aug 16-17 |
| MPU-6050 working | #3 | Aug 18 |
| Servos responding | #4, #5 | Aug 19-20 |
| RadioLink receiver working | #11 | Aug 26 |
| BOM finalized | #12 | Aug 27 |
| Project shift & resubmitted | #13 | Aug 28 |
| Mercury OS planned | #14 | Aug 29 |
| MPU + SBUS + PID code ready | #15 | Aug 30 |
| RF packet designed | #16 | Aug 31 |
| Sensor testing started | #17 | Sep 1 |

---

## 💡 Lessons Learned

1. **Always check voltage levels** - Teensy is 3.3V, not 5V tolerant!
2. **Pull-up resistors matter** - ICM-20948 needs 4.7kΩ on SDA/SCL
3. **Test individual components first** - Debug one thing at a time
4. **Document everything** - Dev logs help track progress
5. **Ask for help** - My tutor lending me parts made this possible
6. **Failure is part of learning** - The ICM didn't work, but switching to MPU-6050 got results
7. **Listen to feedback** - Shifting project direction based on Stardance feedback was the right call
8. **Plan before coding** - Mercury OS planning saved time and confusion
9. **Add sensors one at a time** - Makes troubleshooting much easier
10. **MQ-135 is a relative sensor** - Needs calibration for accurate readings

---

## 🙏 Acknowledgments

- **My Tutor** - For lending me the Teensy 4.1, ICM-20948, and other components
- **The Arduino Community** - For open-source libraries and support
- **The Teensy Community** - For the incredible Teensy platform

---

*Built with passion, powered by curiosity, and tested on borrowed equipment.*  
*Fly safe, have fun, and learn something new.*

---

**Last Updated:** September 1, 2026

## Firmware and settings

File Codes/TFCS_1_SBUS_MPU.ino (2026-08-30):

/*
 * TFCS-1: SBUS + MPU + PID (Self Correcting)
 * MPU reads tilt, SBUS reads sticks, PID corrects
 * 
 * Pins:
 * MPU: SDA→A4, SCL→A5, 3.3V, GND
 * SBUS: Pin 3
 * Servos: Elevator→5, Rudder→6, L Aileron→9, R Aileron→10
 */

#include <Wire.h>
#include <Servo.h>
#include <sbus.h>

// ===== SBUS =====
SBUS sbus;

// ===== SERVOS =====
Servo elevator;
Servo rudder;
Servo leftAil;
Servo rightAil;

// ===== MPU =====
#define MPU_ADDR 0x68

// ===== VARIABLES =====
float roll, pitch;
int rollPID, pitchPID;
int stickAIL, stickELE, stickRUD, stickTHR;

// ===== PID GAINS =====
float Kp_roll = 2.5;
float Ki_roll = 0.0;
float Kd_roll = 0.5;

float Kp_pitch = 2.5;
float Ki_pitch = 0.0;
float Kd_pitch = 0.5;

// ===== PID MEMORY =====
float rollError_prev = 0;
float pitchError_prev = 0;
float rollIntegral = 0;
float pitchIntegral = 0;

// ===== SETUP =====
void setup() {
  Serial.begin(115200);
  Wire.begin();
  Wire.setClock(400000);

  // --- SBUS ---
  sbus.begin(3, sbusNonBlocking);

  // --- SERVOS ---
  elevator.attach(5);
  rudder.attach(6);
  leftAil.attach(9);
  rightAil.attach(10);
  elevator.write(90);
  rudder.write(90);
  leftAil.write(90);
  rightAil.write(90);

  // --- MPU ---
  Wire.beginTransmission(MPU_ADDR);
  Wire.write(0x6B);
  Wire.write(0x00);
  Wire.endTransmission();
  delay(100);

  Serial.println("=== TFCS-1 STABILIZED MODE ===");
  Serial.println("MPU + SBUS + PID");
  Serial.println("-----------------------------------");
}

// ===== LOOP =====
void loop() {
  // ===== 1. READ MPU =====
  Wire.beginTransmission(MPU_ADDR);
  Wire.write(0x3B);
  Wire.endTransmission(false);
  Wire.requestFrom(MPU_ADDR, 6, true);

  if (Wire.available() >= 6) {
    int16_t ax = Wire.read() << 8 | Wire.read();
    int16_t ay = Wire.read() << 8 | Wire.read();
    int16_t az = Wire.read() << 8 | Wire.read();

    roll = atan2(ay, az) * 180 / PI;
    pitch = atan2(-ax, sqrt(ay * ay + az * az)) * 180 / PI;
  }

  // ===== 2. READ SBUS =====
  if (sbus.hasSignal()) {
    stickAIL = sbus.getChannel(1);   // Aileron
    stickELE = sbus.getChannel(2);   // Elevator
    stickTHR = sbus.getChannel(3);   // Throttle
    stickRUD = sbus.getChannel(4);   // Rudder
  }

  // ===== 3. CONVERT STICKS TO TARGET ANGLES =====
  float targetRoll = map(stickAIL, 300, 1700, -30, 30);
  float targetPitch = map(stickELE, 300, 1700, -20, 20);

  // ===== 4. PID CALCULATION (ROLL) =====
  float rollError = targetRoll - roll;
  rollIntegral += rollError * 0.02;
  rollIntegral = constrain(rollIntegral, -10, 10);
  float rollDerivative = (rollError - rollError_prev) / 0.02;
  rollError_prev = rollError;

  rollPID = Kp_roll * rollError + Ki_roll * rollIntegral + Kd_roll * rollDerivative;
  rollPID = constrain(rollPID, -30, 30);

  // ===== 5. PID CALCULATION (PITCH) =====
  float pitchError = targetPitch - pitch;
  pitchIntegral += pitchError * 0.02;
  pitchIntegral = constrain(pitchIntegral, -10, 10);
  float pitchDerivative = (pitchError - pitchError_prev) / 0.02;
  pitchError_prev = pitchError;

  pitchPID = Kp_pitch * pitchError + Ki_pitch * pitchIntegral + Kd_pitch * pitchDerivative;
  pitchPID = constrain(pitchPID, -20, 20);

  // ===== 6. CALCULATE SERVO POSITIONS =====
  int elevPos = 90 + pitchPID;
  elevPos = constrain(elevPos, 20, 160);

  int leftAilPos = 90 + rollPID;
  leftAilPos = constrain(leftAilPos, 20, 160);

  int rightAilPos = 90 - rollPID;
  rightAilPos = constrain(rightAilPos, 20, 160);

  int rudPos = map(stickRUD, 300, 1700, 40, 140);
  rudPos = constrain(rudPos, 30, 150);

  // ===== 7. DEADBAND (Stops buzzing) =====
  if (abs(roll) < 0.8) {
    leftAilPos = 90;
    rightAilPos = 90;
  }
  if (abs(pitch) < 0.8) {
    elevPos = 90;
  }

  // ===== 8. MOVE SERVOS =====
  elevator.write(elevPos);
  rudder.write(rudPos);
  leftAil.write(leftAilPos);
  rightAil.write(rightAilPos);

  // ===== 9. TELEMETRY =====
  Serial.print("R:");
  Serial.print(roll, 1);
  Serial.print(" P:");
  Serial.print(pitch, 1);
  Serial.print(" | T_R:");
  Serial.print(targetRoll, 1);
  Serial.print(" T_P:");
  Serial.print(targetPitch, 1);
  Serial.print(" | PID_R:");
  Serial.print(rollPID, 1);
  Serial.print(" PID_P:");
  Serial.print(pitchPID, 1);
  Serial.print(" | E:");
  Serial.print(elevPos);
  Serial.print(" L:");
  Serial.print(leftAilPos);
  Serial.print(" R:");
  Serial.print(rightAilPos);
  Serial.print(" Rud:");
  Serial.println(rudPos);

  delay(20); // 50Hz
}

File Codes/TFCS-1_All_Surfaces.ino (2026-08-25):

/*
 * TFCS-1: Teensy Flight Computer & Climate Suite
 * Full Flight Control - Ailerons, Rudder, Elevator
 * 
 * MPU-6050 IMU reads roll and pitch angles
 * Servos respond to stabilize the aircraft
 * 
 * Pin Mapping:
 * - Pin 5:  Elevator  (Pitch Control)
 * - Pin 6:  Rudder    (Yaw Control)
 * - Pin 9:  Left Aileron  (Roll Control)
 * - Pin 10: Right Aileron (Roll Control)
 * 
 * Built by Rithish - 16-year-old maker
 * GitHub: github.com/R1th1shwork/TFCS-1
 */

#include <Wire.h>
#include <Servo.h>

#define MPU_ADDR 0x68

// Servo objects
Servo elevator;     // Pin 5
Servo rudder;       // Pin 6
Servo leftAileron;  // Pin 9
Servo rightAileron; // Pin 10

// Raw angles from IMU
float rawPitch = 0.0;
float rawRoll = 0.0;

// Filtered angles (smooth, no jitter)
float filteredPitch = 0.0;
float filteredRoll = 0.0;

// Low-Pass Filter Alpha (0.0 to 1.0)
// Lower = smoother but slower response
// Higher = faster response but more jitter
const float ALPHA = 0.15;

// Max tilt angles for full servo deflection
const float MAX_PITCH = 20.0;  // degrees
const float MAX_ROLL = 30.0;   // degrees

// Servo positions
int elevatorPos = 90;
int rudderPos = 90;
int leftAileronPos = 90;
int rightAileronPos = 90;

void setup() {
  Serial.begin(115200);
  Wire.begin();
  Wire.setClock(400000);
  
  // Attach servos to pins
  elevator.attach(5);
  rudder.attach(6);
  leftAileron.attach(9);
  rightAileron.attach(10);
  
  // Center all servos
  elevator.write(90);
  rudder.write(90);
  leftAileron.write(90);
  rightAileron.write(90);
  
  // Wake up MPU-6050
  Wire.beginTransmission(MPU_ADDR);
  Wire.write(0x6B);
  Wire.write(0x00);
  Wire.endTransmission();
  
  delay(100);
  
  // Check if MPU is connected
  Wire.beginTransmission(MPU_ADDR);
  if (Wire.endTransmission() == 0) {
    Serial.println("✅ MPU-6050 FOUND!");
  } else {
    Serial.println("❌ MPU-6050 NOT FOUND!");
    Serial.println("Check: 5V, GND, A4(SDA), A5(SCL)");
    while (1) {}  // Stop here
  }
  
  Serial.println("=== TFCS-1 FLIGHT CONTROLLER ===");
  Serial.println("Elevator  : Pin 5  (Pitch)");
  Serial.println("Rudder    : Pin 6  (Yaw)");
  Serial.println("Left Aileron : Pin 9  (Roll)");
  Serial.println("Right Aileron: Pin 10 (Roll)");
  Serial.println("-----------------------------------");
  Serial.println("Tilt the board to see servos move!");
  Serial.println("-----------------------------------");
}

void loop() {
  // Read accelerometer data (6 bytes from 0x3B)
  Wire.beginTransmission(MPU_ADDR);
  Wire.write(0x3B);
  Wire.endTransmission(false);
  Wire.requestFrom(MPU_ADDR, 6, true);
  
  if (Wire.available() >= 6) {
    int16_t ax = Wire.read() << 8 | Wire.read();
    int16_t ay = Wire.read() << 8 | Wire.read();
    int16_t az = Wire.read() << 8 | Wire.read();
    
    // Calculate raw angles in degrees
    rawPitch = atan2(-ax, sqrt(ay * ay + az * az)) * 180.0 / PI;
    rawRoll  = atan2(ay, az) * 180.0 / PI;
    
    // Apply low-pass filter to remove jitter
    filteredPitch = (ALPHA * rawPitch) + ((1.0 - ALPHA) * filteredPitch);
    filteredRoll  = (ALPHA * rawRoll)  + ((1.0 - ALPHA) * filteredRoll);
    
    // ===== ELEVATOR (Pitch Control) =====
    // Nose down → Elevator goes UP (40°)
    // Nose up   → Elevator goes DOWN (140°)
    elevatorPos = map(filteredPitch, -MAX_PITCH, MAX_PITCH, 140, 40);
    elevatorPos = constrain(elevatorPos, 20, 160);
    
    // ===== RUDDER (Yaw Control - Reduced Range) =====
    // Tilt left  → Rudder turns left (60°)
    // Tilt right → Rudder turns right (120°)
    rudderPos = map(filteredRoll, -MAX_ROLL, MAX_ROLL, 60, 120);
    rudderPos = constrain(rudderPos, 50, 130);
    
    // ===== AILERONS (Roll Control) =====
    // Tilt left  → Left UP (40°), Right DOWN (140°)
    // Tilt right → Left DOWN (140°), Right UP (40°)
    leftAileronPos = map(filteredRoll, -MAX_ROLL, MAX_ROLL, 40, 140);
    leftAileronPos = constrain(leftAileronPos, 20, 160);
    
    rightAileronPos = map(filteredRoll, -MAX_ROLL, MAX_ROLL, 140, 40);
    rightAileronPos = constrain(rightAileronPos, 20, 160);
    
    // ===== DEADBAND (Stops servo buzzing when level) =====
    if (abs(filteredPitch) < 0.8) elevatorPos = 90;
    if (abs(filteredRoll) < 0.8) {
      rudderPos = 90;
      leftAileronPos = 90;
      rightAileronPos = 90;
    }
    
    // ===== MOVE SERVOS =====
    elevator.write(elevatorPos);
    rudder.write(rudderPos);
    leftAileron.write(leftAileronPos);
    rightAileron.write(rightAileronPos);
    
    // ===== TELEMETRY =====
    Serial.print("P:");
    Serial.print(filteredPitch, 1);
    Serial.print("° (E:");
    Serial.print(elevatorPos);
    Serial.print("°)  R:");
    Serial.print(filteredRoll, 1);
    Serial.print("° (A_L:");
    Serial.print(leftAileronPos);
    Serial.print(" A_R:");
    Serial.print(rightAileronPos);
    Serial.print(" Rudd:");
    Serial.print(rudderPos);
    Serial.println("°)");
  } else {
    Serial.println("⚠️ Waiting for MPU data...");
  }
  
  delay(20);  // 50Hz update rate
}
